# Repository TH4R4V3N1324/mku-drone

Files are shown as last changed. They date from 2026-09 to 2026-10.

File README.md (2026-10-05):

# MKU Drone

Experimental Arduino flight-controller and flight-data-logging workspace.
The repository contains the flight firmware, a standalone IMU logger, Python
utilities for serial tuning and log conversion, and 3D-printable project
models.

This is development hardware and software, not a flight-ready product. Read
the safety notes below before powering motors or ESCs.

## Projects

### [Drone](Drone/README.md)

PlatformIO firmware for an Arduino Uno. The controller:

- Reads an MPU-6050 over I2C and a six-channel PWM receiver.
- Runs experimental roll, pitch, yaw-rate, and hover PID control.
- Mixes the control outputs for four ESCs in an X configuration.
- Supports serial PID tuning and Teleplot-compatible telemetry.

The project README contains the complete pinout, ESC calibration procedure,
control-loop details, known limitations, and tuning instructions.

### [DataLogger](DataLogger/README.md)

PlatformIO firmware for an Arduino Nano. It calibrates an MPU-6050 and writes
fixed-size binary records to a microSD card as `FlightN.bin`. Each record is
40 bytes and contains a timestamp, pitch/roll/yaw, acceleration, and gyro
measurements.

See the project README for the wiring table, binary format, SD-card behavior,
and troubleshooting details.

### [Tools](Tools/)

- [`pid_tuner.py`](Tools/pid_tuner.py) plots live Drone telemetry and sends PID
  commands over the same serial connection.
- [`bin_to_csv.py`](Tools/bin_to_csv.py) converts a DataLogger binary flight
  log into a CSV file, including elapsed time and handling `micros()` rollover.

### [Models](Models/)

3D-printable covers, pads, propeller guards, and test-stand parts for the
hardware.

## Requirements

- [PlatformIO](https://platformio.org/), either the CLI or the VS Code
  extension.
- Python 3 for the desktop tools.
- `pyserial` and `matplotlib` for live PID tuning.

Install the Python dependencies from the repository root:

```text
python -m pip install pyserial matplotlib
```

`bin_to_csv.py` uses only the Python standard library.

## Build and upload

Each firmware project has its own `platformio.ini`. Run PlatformIO from the
project directory you want to build:

```text
cd Drone
pio run
pio run --target upload
pio device monitor --baud 115200
```

For the Nano data logger:

```text
cd DataLogger
pio run
pio run --target upload
pio device monitor --baud 115200
```

PlatformIO normally detects the upload port. If it does not, select the port
in the IDE or add an `upload_port` setting to the relevant
`platformio.ini`.

## Live PID tuning

The Drone firmware can emit Teleplot-compatible telemetry and accept PID
commands over the same serial connection. Enable `TUNE_PID` in
`Drone/src/main.cpp`, upload the firmware, and then run the tuner from the
repository root:

```text
python Tools/pid_tuner.py COM5
```

Replace `COM5` with the board's serial port. If no port is supplied, the tool
lists available serial ports and prompts you to choose one. The default baud
rate is `115200`; it can be changed with `--baud`:

```text
python Tools/pid_tuner.py COM5 --baud 115200 --window 300
```

The tuner plots the selected setpoint, measured value, and PID output while
also forwarding commands typed at its prompt:

| Command | Purpose |
| --- | --- |
| `axis r` | Select roll tuning |
| `axis p` | Select pitch tuning |
| `axis y` | Select yaw tuning |
| `axis h` | Select hover tuning |
| `p <value>` | Set proportional gain |
| `i <value>` | Set integral gain |
| `d <value>` | Set derivative gain |
| `reset` | Clear controller state |
| `show` | Print the active gains |
| `quit` | Exit the tuner |

PID tuning is experimental. Keep propellers removed while changing gains or
testing the control loop.

## Working with flight logs

After stopping or powering down the DataLogger, copy a `FlightN.bin` file from
the microSD card and convert it from the repository root:

```text
python Tools/bin_to_csv.py Flight3.bin
```

This writes `Flight3.csv` beside the input file. To choose a different output
path:

```text
python Tools/bin_to_csv.py Flight3.bin analysis\flight3.csv
```

The logger flushes its buffer every five seconds. Do not remove the SD card
while the logger is running, or the final buffered records may be lost.

## Safety

The Drone firmware is experimental and has not been flight-validated.

- Remove all propellers during setup, wiring, calibration, receiver, IMU,
  ESC, PID, and failsafe testing.
- Keep motors away from people and use a secure test stand where appropriate.
- Power ESCs and motors from a suitable external supply; never power motors
  from the Arduino 5 V pin.
- Verify receiver channel order, IMU orientation, motor numbering, propeller
  direction, ESC arming behavior, and minimum ESC pulses before any powered
  test.
- Treat hover mode as experimental. It is not an arm/disarm mechanism or a
  receiver-loss failsafe.

## Repository layout

```text
Drone/                  Arduino Uno flight-controller firmware
DataLogger/             Arduino Nano binary IMU logger
Tools/                  Python tuning and log-conversion utilities
Models/                 3D-printable hardware models
```

No project license has been specified yet.

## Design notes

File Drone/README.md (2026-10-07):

# Drone Flight Controller

Experimental quadcopter flight-controller firmware for an Arduino Uno. The firmware reads an MPU-6050 IMU and four receiver channels, applies PID corrections, and drives four ESCs through an X-configuration motor mixer.

This is a development prototype, not flight-ready software. Keep propellers removed during development and bench testing, and keep motors away from people.

## Hardware and wiring

- Arduino Uno
- MPU-6050 on I2C at address `0x68`
- Four ESCs and brushless motors
- Receiver with four PWM channels

### Receiver inputs

| Channel | Arduino pin |
| --- | ---: |
| Throttle | 9 |
| Roll | 11 |
| Pitch | 10 |
| Yaw | 8 |
| AUX1 | 12 |
| AUX2 | 13 |

### Motor outputs

| Motor | Arduino pin | Mixer position |
| --- | ---: | --- |
| Motor 1 | 4 | Front left |
| Motor 2 | 5 | Front right |
| Motor 3 | 6 | Rear right |
| Motor 4 | 7 | Rear left |

Connect the receiver and IMU grounds to Arduino ground. Power the ESCs and motors from an appropriate external supply; never power them from the Arduino 5 V pin.

## Requirements

- [PlatformIO](https://platformio.org/)
- Arduino framework for the Uno

The firmware uses the Arduino framework and its built-in `Wire` library for the IMU's I2C connection. No additional PlatformIO libraries are currently required.

## Build and upload

Run these commands from the `Drone` directory:

```text
pio run
pio run --target upload
pio device monitor --baud 115200
```

Select the upload port in PlatformIO or add an `upload_port` setting to `platformio.ini` when automatic port detection does not find the board.

## ESC calibration

ESC calibration is built into the flight-controller firmware and is selected with the `CALIBRATE_ESCS` flag in `src/main.cpp`. When enabled, the firmware sends the same calibration signal to all four ESC outputs (Arduino pins `4-7`): maximum throttle for 15 seconds, followed by minimum throttle for 10 seconds. It then stops and does not enter the normal flight loop.

With propellers removed:

1. Set `CALIBRATE_ESCS` to `1` in `src/main.cpp`.
2. Upload the firmware with the ESCs ready to receive power, but with propellers removed.
3. Power the Arduino and ESCs when prompted by the serial messages, then listen for the ESC confirmation tones.
4. Wait through the 15-second maximum-throttle phase and the 10-second minimum-throttle phase.
5. Power-cycle the ESCs after the firmware reports that calibration pulses are complete.
6. Set `CALIBRATE_ESCS` back to `0` and upload the firmware again before flying.

The calibration routine prints its progress at `115200` baud and intentionally halts after sending both pulse ranges. Keep the motors disconnected or the propellers removed, and use a common ground between the Arduino and ESC signal ground.

## IMU level calibration

"Level" is defined by accelerometer offsets that depend on how the IMU is mounted, so they are measured once and stored in EEPROM. The gyro bias drifts with temperature and is still measured at every boot.

1. Set `CALIBRATE_IMU` to `1` in `src/main.cpp` and upload.
2. Open the serial monitor at `115200` baud.
3. Put a spirit level on the frame (not the table) and shim the drone until the frame is level.
4. Follow the prompts: five rounds of about 6 seconds each. Between rounds, pick the drone up, tilt it around, and set it back down level, then send any key to start the next round. Rounds where the drone moved are repeated.
5. The firmware prints each round, the average, and the spread between rounds. It only saves to EEPROM if all rounds agree within `0.3` degrees. A larger spread usually means a soft surface or a loose IMU mount.
6. Set `CALIBRATE_IMU` back to `0` and upload again before flying.

If it still drifts consistently in hover, adjust `ROLL_TRIM_DEG` and `PITCH_TRIM_DEG` in `src/main.cpp` in steps of about `0.5` degrees. Without position sensing (optical flow or GPS) some drift with air movement is expected.

## Firmware behavior

At startup the firmware initializes serial communication at `115200` baud, wakes the MPU-6050, measures the gyro bias (retrying until the drone is still), loads the level calibration from EEPROM, and seeds the angle estimate from the accelerometer. If no valid calibration is stored, it measures level at boot instead and prints a warning. It then initializes the receiver, starts the ESC output at minimum throttle, and waits two seconds. Arming requires a live receiver link and the throttle seen at minimum first.

The default loop runs the experimental PID control path. It:

1. Reads the IMU and receiver.
2. Estimates vertical velocity from filtered, tilt-compensated accelerometer data.
3. Uses the throttle stick directly and stops all motors when throttle is at or below 5%, unless hover mode is active.
4. Converts receiver commands to roll, pitch, and yaw-rate setpoints.
5. Computes cascaded roll and pitch corrections (angle loop feeding a gyro rate loop), the yaw rate correction, and, when active, the hover PID output.
6. Mixes the commands and writes normalized `0.0-1.0` motor speeds.

### Hover mode

Hover mode is enabled with `AUX1` and uses `AUX2` to command vertical movement:

- Set `AUX1` high while the drone is airborne, the throttle is above 20%, and estimated vertical speed remains below `0.3 m/s` for `0.5` seconds. The firmware captures the filtered throttle value as the hover throttle and resets the hover controller for a bumpless transition.
- While active, `AUX2` commands a climb or descent rate from approximately `-1` to `+1 m/s`. A `0.1 m/s` deadband prevents small stick movements from causing corrections.
- The hover controller adjusts throttle around the captured value, limits the correction to a band around that value, applies a slew rate, and compensates for roll and pitch tilt. Throttle remains constrained between the hover floor and `MAX_THROTTLE`.
- Set `AUX1` low to leave hover mode and return to direct throttle control. The transition ramps from the current hover throttle toward the stick command; moving the stick to the low-throttle cutoff still stops the motors immediately. Hover mode is also not an arm/disarm or receiver-loss failsafe.

Hover mode is experimental. The vertical-velocity estimate is derived from integrated accelerometer data with filtering and leakage, so drift and acceleration bias can affect altitude behavior. Test it with propellers removed first and be ready to disable `AUX1`.

Set `TUNE_PID` to `1` in `src/main.cpp` to enable live PID command handling and telemetry. The `test()` function is available for receiver and mixer checks without PID control; enable it in `loop()` only with propellers removed.

## Live PID tuning

The firmware emits Teleplot-compatible telemetry for the selected axis. The Python helper in `../Tools/pid_tuner.py` plots that telemetry and sends gain changes over the same serial connection.

From the repository root:

```text
python -m pip install pyserial matplotlib
python Tools/pid_tuner.py COM5
```

Use the commands `axis rr` or `axis pr` to select the roll or pitch rate (inner) loop, `axis r` or `axis p` for the roll or pitch angle (outer) loop, and `axis y` or `axis h` for yaw rate or hover tuning. Tune the rate loops first. Use `p <value>`, `i <value>`, and `d <value>` to change gains, `reset` to clear controller state, and `show` to print the active gains. Replace `COM5` with the board's serial port.

## Project structure

```text
include/                 Public firmware headers
  imu.h                   MPU-6050 and orientation interface
  escOutput.h             Timer1 ESC output interface
  motorMixer.h            Quad-X mixer interface
  pid.h                   PID controller
  receiver.h              PWM receiver interface
  serialTuner.h           Runtime PID tuning commands
  calibrationStore.h      EEPROM storage for the IMU level calibration
src/                     Firmware implementation
  main.cpp                Setup, control loop, telemetry, calibration modes, and test loop
  imu.cpp                 MPU-6050 reading, calibration, and complementary filter
  calibrationStore.cpp    EEPROM load/save with checksum and validation
  escOutput.cpp           Timer1 ESC pulse generation
  motorMixer.cpp          Quad-X mixing
  receiver.cpp            Receiver pulse decoding
platformio.ini            PlatformIO configuration
```

## Known limitations and pre-flight work

- There is no explicit arm/disarm state or receiver-loss failsafe beyond invalid channels becoming zero.
- Yaw is integrated from the gyro and will drift without a heading reference.
- The PID gains are experimental and the controller has not been flight-validated.
- Verify receiver channel order, IMU orientation, motor numbering, propeller direction, ESC arming behavior, and minimum ESC pulses with propellers removed.
- Test receiver loss, IMU failure, disarming, and power cycling with propellers removed.

## License

No license has been specified for this project yet.

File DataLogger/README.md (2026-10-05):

# DataLogger

PlatformIO firmware for an Arduino Nano that reads an MPU-6050 and records IMU data to a microSD card as binary records.

## Hardware and wiring

- Arduino Nano with the ATmega328P
- MPU-6050 at I2C address `0x68`
- microSD card module compatible with the SdFat library

### MPU-6050

Connect the sensor using the Nano's standard I2C pins:

| MPU-6050 signal | Arduino Nano pin |
| --- | --- |
| SDA | A4 |
| SCL | A5 |
| VCC | 5V |
| GND | GND |

The firmware uses the I2C address `0x68`, so the sensor's address-select pin must be configured accordingly.

### SD card module

The chip-select pin is fixed to D10. The SPI connections are:

| SD signal | Arduino Nano pin |
| --- | --- |
| CS | D10 |
| MOSI | D11 |
| MISO | D12 |
| SCK | D13 |
| VCC | 5V |
| GND | GND |

## Firmware behavior

At startup, the firmware:

1. Starts serial output at `115200` baud.
2. Starts I2C at 400 kHz and initializes the MPU-6050 for its 1 kHz internal sample rate with the digital low-pass filter disabled.
3. Calibrates the sensor using 2,000 stationary samples. Keep the board still during this step.
4. Initializes the SD card on chip select D10 at a conservative 8 MHz SPI speed for reliable writes.
5. Reads `logNum.txt`, increments its value, and writes the updated value back.
6. Creates a new binary file named `FlightN.bin`, where `N` is the incremented flight number.

If SD initialization or file creation fails, the firmware prints an error and stops in an infinite loop. Existing log files are not overwritten because the flight number is persisted in `logNum.txt`.

The main loop reads the IMU, calculates orientation, and appends one fixed 40-byte binary record to a 128-byte RAM buffer. Each record contains a `uint32_t` microsecond timestamp followed by nine IEEE-754 `float32` values: pitch, roll, yaw, acceleration X/Y/Z, and gyro X/Y/Z. The buffer is written to the card as raw bytes when full and is flushed to the filesystem every five seconds. This avoids CSV conversion and substantially reduces the data size. Serial timing output is disabled in the hot loop because transmitting diagnostics at 115200 baud significantly reduces the maximum logging rate. Remove the SD card only after stopping or powering down the logger so the last buffered data is not lost.

## Binary format

Binary files contain consecutive 40-byte little-endian records with no header:

```text
uint32 timestamp_us
float32 pitch
float32 roll
float32 yaw
float32 accel_x
float32 accel_y
float32 accel_z
float32 gyro_x
float32 gyro_y
float32 gyro_z
```

For example, Python can decode a file with:

```python
import numpy as np

record_dtype = np.dtype([
    ("timestamp_us", "<u4"),
    ("pitch", "<f4"),
    ("roll", "<f4"),
    ("yaw", "<f4"),
    ("accel_x", "<f4"),
    ("accel_y", "<f4"),
    ("accel_z", "<f4"),
    ("gyro_x", "<f4"),
    ("gyro_y", "<f4"),
    ("gyro_z", "<f4"),
])
records = np.fromfile("FlightN.bin", dtype=record_dtype)
```

| Column | Unit | Description |
| --- | --- | --- |
| Timestamp | us | Arduino `micros()` value since boot |
| Pitch | degrees | Complementary-filter pitch estimate |
| Roll | degrees | Complementary-filter roll estimate |
| Yaw | degrees | Gyroscope-integrated yaw estimate; it will drift |
| Accel X/Y/Z | m/s^2 | Accelerometer readings |
| Gyro X/Y/Z | degrees/s | Bias-calibrated and low-pass-filtered angular rates |

The MPU-6050 temperature is read by the IMU class but is not currently written to the binary record.

## Build, upload, and monitor

Install [PlatformIO](https://platformio.org/) through the CLI or the VS Code extension. From this directory, run:

```text
pio run
pio run --target upload
pio device monitor --baud 115200
```

The project is configured for the `nanoatmega328` board and the Arduino framework. The `SdFat` and `SPI` dependencies are declared in `platformio.ini`.

On a successful startup, the serial monitor reports the SD-card status and the name of the active log file. Remove the SD card only after stopping or powering down the logger so the last buffered data is not lost.

## Project layout

```text
include/imu.h       MPU-6050 interface and data accessors
src/imu.cpp         Sensor initialization, calibration, filtering, and orientation
src/main.cpp        SdFat setup, file naming, and buffered binary logging loop
platformio.ini      Nano, framework, monitor, and library configuration
```

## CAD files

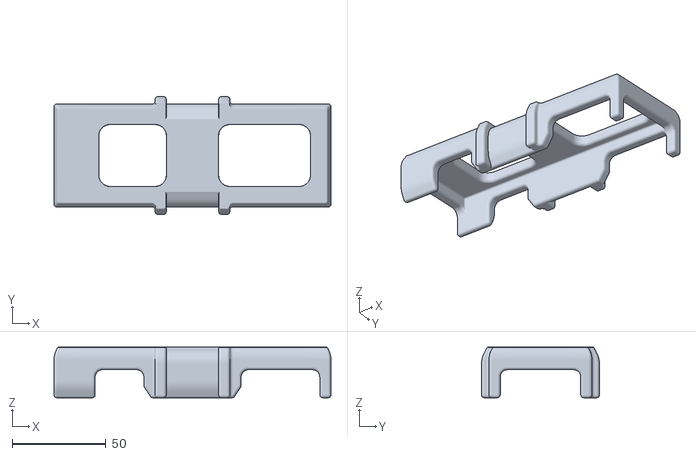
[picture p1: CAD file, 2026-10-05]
Models/Drone/BatteryCoverMk2.stl
148.0 x 63.0 x 27.0

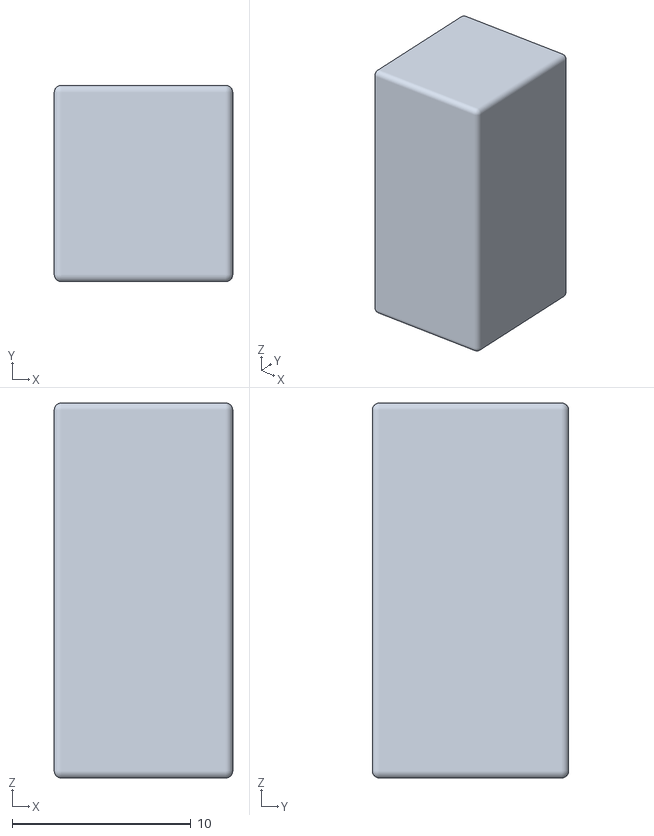
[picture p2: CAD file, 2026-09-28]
Models/Drone/IMU_Pad.stl
10.0 x 11.0 x 21.0

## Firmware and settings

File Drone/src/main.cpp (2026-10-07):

#include <Arduino.h>
#include <Wire.h>
#include <string.h>
#include "imu.h"
#include "motorMixer.h"
#include "escOutput.h"
#include "pid.h"
#include "receiver.h"
#include "serialTuner.h"
#include "calibrationStore.h"

#define TUNE_PID 0        // Set to 1 to enable PID tuning via serial commands
#define CALIBRATE_ESCS 0  // Set to 1 to calibrate ESCs on startup (ensure props are removed)
#define CALIBRATE_IMU 0   // Set to 1 to run the guided IMU level calibration and save it to EEPROM

#if CALIBRATE_ESCS && CALIBRATE_IMU
#error "Enable only one of CALIBRATE_ESCS and CALIBRATE_IMU"
#endif

constexpr float MAX_THROTTLE = 0.85f; // 1850 us, leaving correction headroom

void run();
void disarm();
void test();
[[noreturn]] void haltWithImuError();
#if CALIBRATE_ESCS
void calibrateEscs();
#endif
#if CALIBRATE_IMU
void calibrateImuLevel();
#endif

// ESC signal pins: front left, front right, rear right, rear left (must be on PORTD)
constexpr uint8_t motorPins[ESC_COUNT] = {4, 5, 6, 7};
EscOutput esc;
MotorMixer mixer(esc);
IMU imu;

constexpr uint8_t throttlePin = 9;
constexpr uint8_t rollPin     = 11;
constexpr uint8_t pitchPin    = 10;
constexpr uint8_t yawPin      = 8;
constexpr uint8_t aux1Pin     = 12;
constexpr uint8_t aux2Pin     = 13;
Receiver receiver(throttlePin, rollPin, pitchPin, yawPin, aux1Pin, aux2Pin);

constexpr float ROLL_CORRECTION_LIMIT  = 0.3f;   // PID output range (+/-)
constexpr float PITCH_CORRECTION_LIMIT = 0.3f;   // PID output range (+/-)
constexpr float YAW_CORRECTION_LIMIT   = 0.2f;   // PID output range (+/-)
constexpr float MAX_TILT_ANGLE         = 30.0f;  // deg, full stick roll/pitch
constexpr float MAX_TILT_RATE          = 200.0f; // deg/s, outer angle loop output limit
constexpr float MAX_YAW_RATE           = 180.0f; // deg/s, full stick yaw
constexpr float RATE_D_FILTER_HZ       = 30.0f;  // low-pass on the rate loops' D term only

// Fine level adjustment on top of the EEPROM calibration. If it drifts in hover, trim in
// ~0.5 deg steps; positive values act like holding a little positive roll/pitch stick.
constexpr float ROLL_TRIM_DEG          = 0.0f;
constexpr float PITCH_TRIM_DEG         = 0.0f;
constexpr uint16_t LEVEL_BOOT_SAMPLES  = 2000;   // fallback level measurement at boot if EEPROM is empty (~3 s)

constexpr float HOVER_CORRECTION_LIMIT = 0.25f;  // PID output range (+/-)
constexpr float HOVER_BAND             = 0.25f;  // final throttle stays within hoverThrottle +/- this
constexpr float HOVER_THROTTLE_MIN     = 0.15f;  // floor in hover (must be above the 0.05 motor cutoff)
constexpr float HOVER_SLEW_RATE        = 0.3f;   // max throttle change per second
constexpr float THROTTLE_HANDOFF_RATE  = 1.5f;   // max manual throttle handoff change per second
constexpr float HOVER_MIN_TILT_COS     = 0.7f;   // limits tilt compensation to ~45 degrees
constexpr float ENTRY_MAX_VZ           = 0.3f;   // m/s, must be below this to engage
constexpr float ENTRY_HOLD_S           = 0.5f;   // seconds the conditions must hold
constexpr float ENTRY_MIN_THROTTLE     = 0.2f;   // can't engage hover on the ground
constexpr float CLIMB_DEADBAND         = 0.1f;   // m/s
constexpr float THROTTLE_FILTER_TAU    = 0.3f;   // s, smoothing of stick throttle for capture
constexpr float ACCEL_FILTER_HZ        = 20.0f;  // low-pass on vertical accel
constexpr float VZ_LEAK_TAU            = 2.0f;   // s, drift decay time constant
constexpr float GRAVITY                = 9.80665f; // m/s^2

static bool  hoverActive    = false;
static float vz             = 0.0f;
static float azFilt         = 0.0f;
static float throttleFilt   = 0.0f;
static float hoverThrottle  = 0.0f;
static float hoverCmd       = 0.0f;
static float handoffThrottle = 0.0f;
static bool  throttleHandoff = false;
static float steadyTime     = 0.0f;

constexpr float   ARM_THROTTLE      = 0.08f; // stick above this arms (once unblocked)
constexpr float   IDLE_THROTTLE     = 0.03f; // stick at/below this disarms and unblocks arming
constexpr uint8_t IMU_FAIL_LIMIT    = 25;    // consecutive failed IMU reads (100 ms at 250 Hz) before disarming

static bool    throttleIdle = true;  // motors stopped (disarmed)
static bool    armBlocked   = true;  // must see a valid low throttle before arming (boot, signal loss, IMU failure)
static uint8_t imuFailCount = 0;

PID altitudePID(0.1, 0.0, 0.0, -HOVER_CORRECTION_LIMIT, HOVER_CORRECTION_LIMIT); // PID controller for altitude
// Cascaded attitude control: angle error (deg) -> outer P -> rate setpoint (deg/s) -> inner PID on gyro -> motor correction.
// Roll/pitch gains tuned on a single-axis test rig; yaw is not tuned yet.
PID rollAnglePID(3.0 , 0.0, 0.0, -MAX_TILT_RATE, MAX_TILT_RATE); // outer loop: roll angle -> roll rate setpoint
PID pitchAnglePID(3.0, 0.0, 0.0, -MAX_TILT_RATE, MAX_TILT_RATE); // outer loop: pitch angle -> pitch rate setpoint
PID rollRatePID(0.0045, 0.0008, 0.00002, -ROLL_CORRECTION_LIMIT, ROLL_CORRECTION_LIMIT, RATE_D_FILTER_HZ); // inner loop: roll rate
PID pitchRatePID(0.0045, 0.0008, 0.00002, -PITCH_CORRECTION_LIMIT, PITCH_CORRECTION_LIMIT, RATE_D_FILTER_HZ); // inner loop: pitch rate
PID yawPID(0.004, 0.002, 0.0, -YAW_CORRECTION_LIMIT, YAW_CORRECTION_LIMIT, RATE_D_FILTER_HZ); // yaw rate
SerialTuner tuner(rollAnglePID, rollRatePID, pitchAnglePID, pitchRatePID, yawPID, altitudePID);

unsigned long previousLoopTime;
unsigned long lastTelemetryTime = 0;

void setup() {
  Serial.begin(115200);
  #if CALIBRATE_ESCS
    calibrateEscs();
  #else
    Wire.begin();
    Wire.setClock(400000); // Set I2C clock speed to 400kHz
    Wire.setWireTimeout(3000, true); // Set I2C timeout to 3 ms (value is in us) and reset the bus on timeout

    imu.init();
    #if CALIBRATE_IMU
      calibrateImuLevel(); // does not return
    #endif

    // Gyro bias drifts with temperature, so measure it every boot (works on uneven ground)
    if (!imu.calibrateGyro()) {
      haltWithImuError();
    }

    // Level offsets depend on how the IMU is mounted, so they come from EEPROM
    IMU::LevelCalibration level;
    if (loadLevelCalibration(level)) {
      Serial.println(F("Loaded IMU level calibration from EEPROM."));
    } else {
      Serial.println(F("No saved IMU level calibration - measuring level now, keep the frame level."));
      Serial.println(F("Run CALIBRATE_IMU once for an accurate, repeatable calibration."));
      bool moved = true;
      while (moved) {
        if (!imu.measureLevel(level, LEVEL_BOOT_SAMPLES, moved)) {
          haltWithImuError();
        }
        if (moved) {
          Serial.println(F("Movement detected, retrying - keep the drone still."));
        }
      }
    }
    imu.setLevelCalibration(level);
    if (!imu.resetOrientation()) {
      haltWithImuError();
    }

    receiver.init();
    esc.begin(motorPins); // Timer1 keeps sending min-throttle pulses from here on
    delay(2000);
    mixer.stopAllMotors();
    previousLoopTime = micros();
  #endif
}

void loop() {
  esc.waitForNextCycle(); // fixed ESC_UPDATE_RATE_HZ control loop
  if (TUNE_PID) {tuner.update();}
  run();
  //test();
}

/**
 * @brief Main control loop for the drone
 * @details Reads data from the IMU and receiver, computes PID outputs, and mixes motor speeds
 * @return None
 */
void run() {
  unsigned long now = micros();
  float dt = (now - previousLoopTime) / 1000000.0f;
  previousLoopTime = now;
  if (dt <= 0.0f || dt > 0.1f) dt = 1.0f / ESC_UPDATE_RATE_HZ;

  receiver.readData();

  // Keep flying on the last sample through brief I2C glitches, but disarm if the IMU stays unreachable
  if (imu.readData()) {
    imuFailCount = 0;
  } else if (imuFailCount < IMU_FAIL_LIMIT) {
    ++imuFailCount;
  }
  if (imuFailCount >= IMU_FAIL_LIMIT) {
    disarm();
    return;
  }

  float stickThrottle = receiver.getThrottle();
  bool hoverSwitch = receiver.getAux1() > 0.5f;

  // Filtered stick throttle (used for hover capture)
  throttleFilt += (dt / (THROTTLE_FILTER_TAU + dt)) * (stickThrottle - throttleFilt);

  // Vertical velocity estimate (runs every loop so it's valid on entry)
  float rollRad  = imu.getRoll()  * DEG_TO_RAD;
  float pitchRad = imu.getPitch() * DEG_TO_RAD;
  float tiltCos  = cosf(rollRad) * cosf(pitchRad);

  float azWorld = imu.getAccelZ() * tiltCos - GRAVITY;   // flip sign if your Z axis points down
  const float accelTau = 1.0f / (2.0f * PI * ACCEL_FILTER_HZ);
  azFilt += (dt / (accelTau + dt)) * (azWorld - azFilt);

  vz += azFilt * dt;
  vz -= vz * dt / VZ_LEAK_TAU;                           // dt-independent leak
  if (!hoverActive && stickThrottle <= 0.05f) vz = 0.0f; // on the ground / idle

  // Hover entry / exit
  if (!hoverSwitch) {
    if (hoverActive) {
      handoffThrottle = hoverCmd / fmaxf(tiltCos, HOVER_MIN_TILT_COS);
      handoffThrottle = constrain(handoffThrottle, HOVER_THROTTLE_MIN, MAX_THROTTLE);
      throttleHandoff = true;
    }
    hoverActive = false;
    steadyTime = 0.0f;
  } else if (!hoverActive) {
    bool steady = !throttleIdle && fabsf(vz) < ENTRY_MAX_VZ && throttleFilt > ENTRY_MIN_THROTTLE; // never engage while disarmed
    steadyTime = steady ? steadyTime + dt : 0.0f;

    if (steadyTime >= ENTRY_HOLD_S) {
      hoverActive   = true;
      hoverThrottle = throttleFilt;   // captured hover throttle
      hoverCmd      = hoverThrottle;  // start the slew limiter here (bumpless)
      throttleHandoff = false;
      vz            = 0.0f;
      altitudePID.reset();
    }
  }

  // Throttle
  float throttle;
  float hoverSetpoint = 0.0f;
  float hoverMeasured = vz;
  float hoverCorrection = 0.0f;
  if (hoverActive) {
    float climbRate = receiver.getAux2() * 2.0f - 1.0f;  // +/-1 m/s
    if (fabsf(climbRate) < CLIMB_DEADBAND) climbRate = 0.0f;

    hoverSetpoint = climbRate;
    hoverCorrection = altitudePID.compute(hoverSetpoint, hoverMeasured, dt);

    // Clamp to a band around the captured throttle, above the floor
    float lower  = fmaxf(hoverThrottle - HOVER_BAND, HOVER_THROTTLE_MIN);
    float upper  = hoverThrottle + HOVER_BAND;
    float target = constrain(hoverThrottle + hoverCorrection, lower, upper);

    // Slew limit
    float maxStep = HOVER_SLEW_RATE * dt;
    hoverCmd += constrain(target - hoverCmd, -maxStep, maxStep);

    // Tilt compensation
    throttle = hoverCmd / fmaxf(tiltCos, HOVER_MIN_TILT_COS);
    throttle = constrain(throttle, HOVER_THROTTLE_MIN, MAX_THROTTLE);
  } else {
    if (throttleIdle) {
      // Only arm after a live link has shown the throttle low, so booting or reconnecting with the stick up can't spin the motors
      if (!receiver.hasSignal()) {
        armBlocked = true;
      } else if (stickThrottle <= IDLE_THROTTLE) {
        armBlocked = false;
      }

      if (!armBlocked && stickThrottle > ARM_THROTTLE) {
        rollAnglePID.reset();
        pitchAnglePID.reset();
        rollRatePID.reset();
        pitchRatePID.reset();
        yawPID.reset();
        altitudePID.reset();
        throttleIdle = false;
      }
    } else {
      if (stickThrottle <= IDLE_THROTTLE) throttleIdle = true;
    }

    if (throttleIdle) {
      throttleHandoff = false;
      mixer.stopAllMotors();
      return;
    }

    if (throttleHandoff) {
      float maxStep = THROTTLE_HANDOFF_RATE * dt;
      handoffThrottle += constrain(stickThrottle - handoffThrottle, -maxStep, maxStep);
      throttle = handoffThrottle;
      if (fabsf(stickThrottle - handoffThrottle) <= maxStep) {
        throttleHandoff = false;
      }
    } else {
      throttle = stickThrottle;
    }
    throttle = constrain(throttle, 0.0f, MAX_THROTTLE);
  }

  float rollSetpoint = receiver.getRoll() * MAX_TILT_ANGLE + ROLL_TRIM_DEG;
  float pitchSetpoint = receiver.getPitch() * MAX_TILT_ANGLE + PITCH_TRIM_DEG;
  float yawRateSetpoint = receiver.getYaw() * MAX_YAW_RATE;

  // Outer loop: angle error -> desired rotation rate
  float rollRateSetpoint = rollAnglePID.compute(rollSetpoint, imu.getRoll(), dt);
  float pitchRateSetpoint = pitchAnglePID.compute(pitchSetpoint, imu.getPitch(), dt);

  // Inner loop: track the rate with the gyro directly (roll integrates gyro Y, pitch gyro X)
  float rollOutput = rollRatePID.compute(rollRateSetpoint, imu.getGyroY(), dt);
  float pitchOutput = pitchRatePID.compute(pitchRateSetpoint, imu.getGyroX(), dt);
  float yawOutput = yawPID.compute(yawRateSetpoint, imu.getGyroZ(), dt);

  if (TUNE_PID && millis() - lastTelemetryTime >= 50) {
    lastTelemetryTime = millis();
    const char* axis = tuner.getActiveAxisName();
    float setpointToPrint, measuredToPrint, outputToPrint;
    if (strcmp(axis, "roll") == 0) {
      setpointToPrint = rollSetpoint;
      measuredToPrint = imu.getRoll();
      outputToPrint = rollRateSetpoint;
    } else if (strcmp(axis, "rollrate") == 0) {
      setpointToPrint = rollRateSetpoint;
      measuredToPrint = imu.getGyroY();
      outputToPrint = rollOutput;
    } else if (strcmp(axis, "pitch") == 0) {
      setpointToPrint = pitchSetpoint;
      measuredToPrint = imu.getPitch();
      outputToPrint = pitchRateSetpoint;
    } else if (strcmp(axis, "pitchrate") == 0) {
      setpointToPrint = pitchRateSetpoint;
      measuredToPrint = imu.getGyroX();
      outputToPrint = pitchOutput;
    } else if (strcmp(axis, "yaw") == 0) {
      setpointToPrint = yawRateSetpoint;
      measuredToPrint = imu.getGyroZ();
      outputToPrint = yawOutput;
    } else if (strcmp(axis, "hover") == 0) {
      setpointToPrint = hoverSetpoint;
      measuredToPrint = hoverMeasured;
      outputToPrint = hoverCorrection;
    } else {
      setpointToPrint = 0.0f;
      measuredToPrint = 0.0f;
      outputToPrint = 0.0f;
    }

    //Plot with Teleplot to tune PID parameters
    Serial.print(">Setpoint:"); Serial.println(setpointToPrint);
    Serial.print(">Actual:"); Serial.println(measuredToPrint);
    Serial.print(">Output:"); Serial.println(outputToPrint);
  }

  mixer.mixMotors(throttle, rollOutput, pitchOutput, yawOutput);
}

/**
 * @brief Stop the motors and require a valid low throttle before arming again
 * @details Also leaves hover mode so it can't re-engage until re-armed.
 * @return None
 */
void disarm() {
  hoverActive     = false;
  throttleHandoff = false;
  steadyTime      = 0.0f;
  throttleIdle    = true;
  armBlocked      = true;
  mixer.stopAllMotors();
}

/**
 * @brief Test the receiver-to-mixer path without running the PID controllers
 * @details Uses the transmitter throttle and small normalized attitude commands
 * so each stick can be checked independently with the propellers removed.
 * @return None
 */
void test() {
  receiver.readData();
  receiver.printData();

  float throttle = receiver.getThrottle();
  float roll = receiver.getRoll() * 0.20f;
  float pitch = receiver.getPitch() * 0.20f;
  float yaw = receiver.getYaw() * 0.20f;

  if (throttle <= 0.05f) {
    mixer.stopAllMotors();
    return;
  }

  mixer.mixMotors(throttle, roll, pitch, yaw);
}

#if CALIBRATE_ESCS
/**
 * @brief Calibrate the ESCs by sending a high throttle signal followed by a low throttle signal
 * @details This function should be called once on startup with the propellers removed.
 * It sends a high throttle signal for 15 seconds (power the ESCs during this), then a low
 * throttle signal for 10 seconds, then halts.
 * @return None
 */
void calibrateEscs() {
  esc.begin(motorPins);

  Serial.println(F("ESC calibration: props OFF."));
  Serial.println(F("Sending MAX throttle — power the ESCs now."));
  unsigned long start = millis();
  while (millis() - start < 15000) {
    mixer.setAllMotors(1.0f); // keep refreshing so the output watchdog doesn't drop to min
  }

  Serial.println(F("Sending MIN throttle — listen for confirmation beeps."));
  start = millis();
  while (millis() - start < 10000) {
    mixer.setAllMotors(0.0f);
  }

  Serial.println(F("Calibration pulses sent. Halting — power-cycle to arm normally."));
  mixer.stopAllMotors();
  while (true) {}   // stop here on purpose, don't fall into run()
}
#endif

/**
 * @brief Report an IMU I2C failure and halt
 * @details Called before the ESC output starts, so the ESCs stay unarmed with no signal.
 * @return Never returns
 */
void haltWithImuError() {
  Serial.println(F("IMU I2C error. Check wiring and power-cycle."));
  while (true) {}
}

#if CALIBRATE_IMU
/**
 * @brief Block until a key is sent over Serial, then discard the rest of the line
 * @return None
 */
static void waitForKey() {
  while (Serial.available()) Serial.read();
  while (!Serial.available()) {}
  delay(50);
  while (Serial.available()) Serial.read();
}

/**
 * @brief Guided IMU level calibration, saved to EEPROM
 * @details Measures level several times, with the drone picked up and set down between
 * rounds, and only saves the average if the rounds agree. Rounds where the drone moved are
 * repeated. Open the serial monitor at 115200 baud; ESCs receive no signal while this runs.
 * @return Never returns
 */
void calibrateImuLevel() {
  constexpr uint8_t ROUNDS = 5;
  constexpr uint16_t SAMPLES_PER_ROUND = 4000; // ~6 s per round
  constexpr float MAX_SPREAD_DEG = 0.3f;       // rounds must agree within this to be saved

  Serial.println(F("IMU level calibration."));
  Serial.println(F("Put a spirit level on the FRAME (not the table) and shim it level."));
  Serial.println(F("Measuring gyro bias - keep it still..."));
  if (!imu.calibrateGyro()) {
    haltWithImuError();
  }

  IMU::LevelCalibration rounds[ROUNDS];
  uint8_t round = 0;
  while (round < ROUNDS) {
    Serial.print(F("Round ")); Serial.print(round + 1); Serial.print('/'); Serial.print(ROUNDS);
    Serial.println(F(": set the drone down level and still, then send any key."));
    waitForKey();
    Serial.println(F("Measuring - don't touch it..."));

    bool moved;
    if (!imu.measureLevel(rounds[round], SAMPLES_PER_ROUND, moved)) {
      haltWithImuError();
    }
    if (moved) {
      Serial.println(F("Movement detected - repeating this round."));
      continue;
    }

    Serial.print(F("  pitch ")); Serial.print(rounds[round].pitchOffset, 3);
    Serial.print(F(" deg | roll ")); Serial.print(rounds[round].rollOffset, 3);
    Serial.print(F(" deg | accelZ offset ")); Serial.print(rounds[round].accelZOffset, 3);
    Serial.println(F(" m/s^2"));
    ++round;
    if (round < ROUNDS) {
      Serial.println(F("Pick it up, tilt it around, then set it back down level."));
    }
  }

  IMU::LevelCalibration mean = {0.0f, 0.0f, 0.0f};
  float minPitch = rounds[0].pitchOffset, maxPitch = minPitch;
  float minRoll = rounds[0].rollOffset, maxRoll = minRoll;
  for (uint8_t i = 0; i < ROUNDS; ++i) {
    mean.pitchOffset += rounds[i].pitchOffset / ROUNDS;
    mean.rollOffset += rounds[i].rollOffset / ROUNDS;
    mean.accelZOffset += rounds[i].accelZOffset / ROUNDS;
    minPitch = fminf(minPitch, rounds[i].pitchOffset);
    maxPitch = fmaxf(maxPitch, rounds[i].pitchOffset);
    minRoll = fminf(minRoll, rounds[i].rollOffset);
    maxRoll = fmaxf(maxRoll, rounds[i].rollOffset);
  }
  const float pitchSpread = maxPitch - minPitch;
  const float rollSpread = maxRoll - minRoll;

  Serial.print(F("Average: pitch ")); Serial.print(mean.pitchOffset, 3);
  Serial.print(F(" deg | roll ")); Serial.print(mean.rollOffset, 3);
  Serial.print(F(" deg | accelZ offset ")); Serial.print(mean.accelZOffset, 3);
  Serial.println(F(" m/s^2"));
  Serial.print(F("Spread between rounds: pitch ")); Serial.print(pitchSpread, 3);
  Serial.print(F(" deg | roll ")); Serial.print(rollSpread, 3);
  Serial.println(F(" deg"));

  if (pitchSpread > MAX_SPREAD_DEG || rollSpread > MAX_SPREAD_DEG) {
    Serial.println(F("Rounds disagree - NOT saved. Check the surface is solid and the IMU mount isn't loose, then retry."));
  } else {
    saveLevelCalibration(mean);
    IMU::LevelCalibration check;
    if (loadLevelCalibration(check)) {
      Serial.println(F("Saved to EEPROM and verified."));
    } else {
      Serial.println(F("Save FAILED verification - offsets out of range? Check the IMU mounting."));
    }
  }
  Serial.println(F("Set CALIBRATE_IMU to 0 and re-upload to fly."));
  while (true) {}
}
#endif

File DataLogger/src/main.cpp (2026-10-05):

#include <Arduino.h>
#include <Wire.h>
#include "imu.h"
#include "log_buffer.h"
#include <SdFat.h>
#include <SPI.h>

#define SD_CS_PIN 10

IMU imu;
SdFat sd;
File32 flightLog;

int flightNum = 0;
unsigned long lastLogTime = 0;

struct BinaryLogRecord {
  uint32_t timestampUs;
  float pitch;
  float roll;
  float yaw;
  float accelX;
  float accelY;
  float accelZ;
  float gyroX;
  float gyroY;
  float gyroZ;
};

static_assert(sizeof(BinaryLogRecord) == 40, "Unexpected binary log record size");

LogBuffer logBuffer;

void stopWithError(const __FlashStringHelper *message) {
  Serial.println(message);
  while (true) {
    delay(1000);
  }
}

void setup() {
  // put your setup code here, to run once:
  Serial.begin(115200);
  Wire.begin();
  Wire.setClock(400000); // Set I2C clock speed to 400kHz
  imu.init(0x68); // Initialize IMU with I2C address 0x68
  imu.calibrate(); // Calibrate the IMU
  SPI.begin();
  pinMode(SD_CS_PIN, OUTPUT);
  digitalWrite(SD_CS_PIN, HIGH);
  // Use a conservative SPI speed for reliable writes with typical SD modules.
  if (!sd.begin(SD_CS_PIN, SD_SCK_MHZ(8))) {
    Serial.println("SD card initialization failed on CS D10");
    Serial.println("Expected SPI pins: MOSI D11, MISO D12, SCK D13");
    stopWithError(F("SdFat error: card.begin() failed"));
  }
  Serial.println("SD card initialized");
  Serial.print("FAT type: ");
  Serial.println(sd.fatType());
  
  File32 logNumFile;
  logNumFile = sd.open("logNum.txt", O_RDONLY);
  if (logNumFile) {
    flightNum = logNumFile.parseInt()+1;
    logNumFile.close();
  }

  logNumFile = sd.open("logNum.txt", O_RDWR | O_CREAT | O_TRUNC);
  if (!logNumFile) {
    sd.errorPrint(&Serial, F("Could not create logNum.txt"));
    stopWithError(F("Could not create logNum.txt"));
  }
  logNumFile.println(flightNum);
  logNumFile.close();
  

  char filename[24];
  strcpy_P(filename, PSTR("Flight"));
  itoa(flightNum, filename + 6, 10);
  strcat_P(filename, PSTR(".bin"));
  flightLog = sd.open(filename, O_RDWR | O_CREAT | O_AT_END);
  if (!flightLog) {
    Serial.print("Could not create ");
    Serial.println(filename);
    sd.errorPrint(&Serial, F("Could not create flight log"));
    stopWithError(F("Could not create flight log"));
  }
  logBuffer.attach(flightLog);
  Serial.print("Logging to ");
  Serial.println(filename);
}

void loop() {
  imu.readData();
  
  unsigned long currentTime = micros();

  float pitch = imu.getPitch();
  float roll = imu.getRoll();
  float yaw = imu.getYaw();
  float accelX = imu.getAccelX();
  float accelY = imu.getAccelY();
  float accelZ = imu.getAccelZ();
  float gyroX = imu.getGyroX();
  float gyroY = imu.getGyroY();
  float gyroZ = imu.getGyroZ();

  BinaryLogRecord record = {
    static_cast<uint32_t>(currentTime),
    pitch,
    roll,
    yaw,
    accelX,
    accelY,
    accelZ,
    gyroX,
    gyroY,
    gyroZ
  };
  if (logBuffer.write(
        reinterpret_cast<const uint8_t *>(&record), sizeof(record)) != sizeof(record)) {
    stopWithError(F("Could not buffer flight log data"));
  }

  // Flush the log to the SD card
  unsigned long time = millis();
  if (time - lastLogTime >= 5000) {
    if (!logBuffer.drain(flightLog)) {
      stopWithError(F("Could not write flight log data"));
    }
    flightLog.flush(); // Ensure data is written to the SD card
    lastLogTime = time;
  }
}

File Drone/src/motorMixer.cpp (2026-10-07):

#include "motorMixer.h"

/**
 * @brief Mix the control signals to determine the motor speeds
 * @details Mixes the throttle, roll, pitch, and yaw signals to determine the speed of each motor.
 * Each motor is held at or above MOTOR_IDLE_SPEED so none stops while armed.
 * @param[in] throttle The throttle input (0.0 to 1.0)
 * @param[in] roll The roll input (0.0 to 1.0)
 * @param[in] pitch The pitch input (0.0 to 1.0)
 * @param[in] yaw The yaw input (0.0 to 1.0)
 * @return None
 */
void MotorMixer::mixMotors(float throttle, float roll, float pitch, float yaw) {
    // Simple mixing algorithm for a quadcopter in X configuration
    const uint16_t pulses[ESC_COUNT] = {
        speedToPulse(fmaxf(throttle + roll + pitch + yaw, MOTOR_IDLE_SPEED)), // Front Left
        speedToPulse(fmaxf(throttle - roll + pitch - yaw, MOTOR_IDLE_SPEED)), // Front Right
        speedToPulse(fmaxf(throttle - roll - pitch + yaw, MOTOR_IDLE_SPEED)), // Rear Right
        speedToPulse(fmaxf(throttle + roll - pitch - yaw, MOTOR_IDLE_SPEED)), // Rear Left
    };
    esc.write(pulses);
}

/**
 * @brief Stop all motors
 * @return None
 */
void MotorMixer::stopAllMotors() {
    esc.writeAll(ESC_MIN_PULSE_US);
}

/**
 * @brief Command all motors to the same speed without mixing (used for ESC calibration)
 * @param[in] speed The speed of every motor (0.0 to 1.0)
 * @return None
 */
void MotorMixer::setAllMotors(float speed) {
    esc.writeAll(speedToPulse(speed));
}

/**
 * @brief Convert a normalized motor speed to an ESC pulse width
 * @param[in] speed The speed of the motor (clamped to 0.0 to 1.0)
 * @return Pulse width in microseconds
 */
uint16_t MotorMixer::speedToPulse(float speed) {
    speed = constrain(speed, 0.0f, 1.0f);
    return static_cast<uint16_t>(ESC_MIN_PULSE_US + speed * (ESC_MAX_PULSE_US - ESC_MIN_PULSE_US));
}

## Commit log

2026-09-22 Refactor motor speed handling and initialize motors in setup
2026-09-22 Add detailed documentation for IMU, Motor, MotorMixer, and Receiver classes
2026-09-22 Enhance IMU and PID classes with detailed documentation for methods
2026-09-22 Update IMU class init method to accept I2C address parameter
2026-09-22 Add TODO section with flight preparation tasks and calibration notes
2026-09-22 Refactor IMU class to use dynamic I2C address and improve data handling methods
2026-09-22 Refactor IMU calibration to average gyro offsets and update data reading method
2026-09-22 Refactor receiver to implement interrupt-based pulse width capture and update readChannel method signature
2026-09-22 Implement Motor class initialization and begin method for motor operation
2026-09-22 Refactor test function to improve receiver-to-mixer path and motor control logic
2026-09-23 Initial commit survivability enhancment STL files
2026-09-23 Refactor PID class to include output limits and improve compute logic; update PID instantiation in main.cpp
2026-09-23 Add getter and setter methods for PID gains
2026-09-23 Add live PID tuner script with serial communication and plotting functionality
2026-09-23 Add SerialTuner class for runtime PID gain tuning over Serial
2026-09-23 Implement MotorMixer methods to initialize and stop all motors
2026-09-23 Add Servo library dependency to platformio.ini
2026-09-23 Add IMU class implementation with initialization, calibration, and data reading methods
2026-09-24 Add ESC calibration functionality with receiver signal processing and gyro integration
2026-09-24 Increase gyroscope calibration sample size from 100 to 2000 for improved accuracy
2026-09-25 Enhance IMU class with additional calibration and filtering features
2026-09-25 Enhance IMU class with additional filtering, calibration improvements, and updated initialization
2026-09-25 Add throttle constraint to run function to prevent instability at higher speeds
    [main.cpp]
2026-09-25 Set I2C clock speed to 400kHz in setup function
2026-09-28 Added IMU_Pad model
    [IMU_Pad.stl]
2026-09-28 Fix receiver pin assignments for roll and yaw channels in main.cpp and README.md
    [main.cpp]
2026-09-28 Add ESC calibration feature and update README with instructions
2026-09-28 Increase ESC calibration duration for better reliability
2026-09-30 Refactor main.cpp to initialize IMU and read orientation data; update platformio.ini for consistency
2026-09-30 Add IMU calibration in setup function for improved accuracy
2026-09-30 Invert pitch channel value in readData function for correct orientation
    [receiver.cpp]
2026-09-30 Refactor integral clamping in PID compute method for improved accuracy
2026-09-30 Implement hover control logic with altitude PID for improved stability
    [main.cpp]
2026-09-30 Add accelZOffset for improved accelerometer calibration and data accuracy
2026-10-01 Update to platform ini file add SD and SPI
2026-10-02 Improve SD card initialization and error handling in setup
    [main.cpp]
2026-10-02 Add accelZOffset for improved IMU calibration and data accuracy
2026-10-02 Add new STL models for Drone and Test Stand components
    - Introduced PropGuardMk2, UnoCoverBody1, and UnoCoverLid1 for the Drone.
    - Added PivotArm, PivotBlock, PivotBush, and StiffeningBar for the Test Stand.
    [IMU_Pad.stl]
2026-10-02 Enhance hover mode functionality with throttle handoff and improved transition control
2026-10-02 Implement throttled flushing of flight log to SD card every 5 seconds
2026-10-05 Add BatteryCoverMk2 STL model and remove obsolete BatteryFrame STL model
    [BatteryCoverMk2.stl]
2026-10-05 Optimize IMU initialization by disabling DLPF for maximum bandwidth and setting sample rate to 1 kHz
2026-10-05 Set IMU sample rate to 1KHz
2026-10-05 Refactor tune PID to run at a fixed 50Hz rate
    [main.cpp]
2026-10-05 Add hysteresis deadband logic to remove motor twitching when idle
    [main.cpp]
2026-10-05 Refactor initialization order so that motor noise indicates completed init
    [main.cpp]
2026-10-07 Replace Servo library with Timer1-driven 250Hz ESC output
    The Servo library only refreshes ESCs at 50Hz, adding up to 20ms of
    output latency. EscOutput drives all four ESC pins from Timer1
    interrupts at a fixed 250Hz, applies all four pulse widths atomically
    each cycle, and falls back to min throttle if not updated for 200ms.
    The control loop is now paced to the same 250Hz cycle.
    MotorMixer now only does the quad-X mixing; the Motor class is removed.
    [escOutput.cpp, escOutput.h, main.cpp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]
2026-10-07 Add deadbands to controller inputs to prevent unintentional movement commands
    [receiver.cpp]
2026-10-07 Refactor roll, pitch and yaw correction limits as constants
    [main.cpp]
2026-10-07 Rework IMU filtering and fix accelerometer calibration
    Increase gyro range to +/-1000 deg/s and accel range to +/-8g so fast
    rotations and motor vibration don't clip. Remove the software gyro
    low-pass filter, which stacked delay on top of the DLPF, and set the
    DLPF to 98Hz to stay below the 125Hz Nyquist of the 250Hz loop.
    Replace the fixed 0.98 complementary filter constant with a 1s time
    constant so accelerometer correction no longer depends on loop rate
    and vibration is filtered out of the angle estimate.
    Fix calibration computing accel angle offsets with mixed g and m/s^2
    units, which underestimated them by ~10x. Calibration and runtime now
    share one accelAngles() helper.
    [imu.cpp, imu.h]
2026-10-07 Add PID reset when transitioning throttleIdle states
    [main.cpp]
2026-10-07 Add IMU timeout and data validation
2026-10-07 Add motor idle floor to prevent motors stopping while armed
    mixMotors() now holds every motor at or above MOTOR_IDLE_SPEED (5%),
    so a large correction at low throttle can no longer stop a motor
    mid-air and risk ESC desync. stopAllMotors() and ESC calibration still
    command a full stop.
    [motorMixer.cpp]
2026-10-07 Switch roll and pitch to cascaded angle/rate control
    Roll and pitch now use an outer P loop on angle that outputs a rate
    setpoint, feeding an inner PID loop on the gyro rate. Damping now
    comes from the gyro directly instead of differentiating the filtered
    angle, and the inner loop rejects disturbances within one cycle.
    PID gains an optional low-pass filter on the D term only, used by the
    rate loops at 30Hz. The serial tuner can select the rate loops
    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
2026-10-07 Add arming and IMU failure safety checks
    Require a live receiver link and a low throttle before arming, so
    booting or reconnecting with the stick raised can't spin the motors.
    Hover mode can no longer engage while disarmed.
    IMU::readData() now reports I2C failures. After 100ms of consecutive
    failures the drone disarms instead of flying on stale attitude data.
    [imu.cpp, imu.h, main.cpp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]
2026-10-07 Clean up receiver channel decoding and rescale stick deadband
    Replace six copies of the pulse validity check with one helper and
    named constants, and remove the aux deadband lines that ran before
    aux1/aux2 were assigned. The deadband now rescales so output rises
    smoothly from 0, which also makes the 0.03 disarm threshold reachable.
    [receiver.cpp]
2026-10-07 Clean up IMU reads and halt on calibration failure
    Share one raw-read function between calibrate() and readData(), read
    register bytes in a defined order, and make scale constants static
    constexpr to save RAM. calibrate() now reports I2C failure and setup
    halts instead of flying with zero offsets. Fix stale comments.
    [imu.cpp, imu.h, main.cpp]
2026-10-07 Add guided IMU level calibration stored in EEPROM
    CALIBRATE_IMU runs a multi-round level calibration with motion
    rejection and only saves to EEPROM if the rounds agree within 0.3 deg.
    Normal boot now measures only the gyro bias (retrying until still),
    loads level offsets from EEPROM, and seeds the angle estimate from the
    accelerometer. Falls back to boot-time level measurement if nothing
    valid is stored. Add ROLL_TRIM_DEG / PITCH_TRIM_DEG for fine trim.
2026-10-07 Add PMW3901 optical flow driver and move receiver off SPI pins
    The receiver used D8-D13, which includes the Uno's hardware SPI pins.
    Receiver channels now map to any pin-change port, so the sticks move to
    A0-A3 and the aux switches to D2/D3, freeing D10-D13 for the PMW3901.
    The flow sensor is initialised at boot; if it is missing the drone
    still flies without drift hold.
2026-10-07 Add optical flow drift hold and flow check mode
    When airborne (hover mode, or stick throttle above 0.2), the PMW3901
    flow is read at 50 Hz, gyro rotation is removed, and two PI loops nudge
    the roll/pitch angle setpoints to drive ground drift to zero. An axis
    is released while its stick is moved and on low surface quality.
    CHECK_FLOW plots flow against the gyro on the bench to set the sensor's
    orientation and scale. Drift gains are tunable as axis dr/dp. READMEs
    cover the new wiring, the flow check, and drift hold.
2026-10-07 Cut motors when tilt exceeds 45 degrees
    If roll or pitch stays beyond 45 degrees for 0.1 s while armed, in
    normal or hover mode, the motors are disarmed and re-arming requires
    the throttle stick at zero first. Covers flips, collisions and the
    drone getting stuck against an obstacle.
2026-10-08 Fixed loop rate to 500hz
2026-10-08 Updated prop guard model
2026-10-13 Fixed opticalflow direction to match physical mounting
2026-10-13 Added method to enable breakout board LEDs
2026-10-13 Calibrate optical flow mounting and remap receiver pins
    Flip both flow signs and raise FLOW_RAD_PER_COUNT to 1.9e-3 after
    CHECK_FLOW showed flow running opposite to rotation at ~0.66 gain.
    Rotation now cancels (gain ~1.0, corr +0.94 on both axes).
    Lower drift hold P from 8 to 6 to stop a small oscillation, and move
    throttle/roll/pitch to A2/A0/A1 to match the receiver wiring.
2026-10-13 Hold ESC pins low during setup and stop below calibrated minimum
    The ESC signal pins floated through IMU calibration while the ESCs were
    already powered, so they could arm on noise. Drive them low from the
    start of setup(); esc.begin() stays at the end so the arming tones
    still mark calibration done.
    Stopped motors now get a 950 us pulse (ESC_STOP_PULSE_US), below the
    1000 us calibrated minimum, so interrupt latency that lengthens pulses
    can't spin them. Throttle still maps to 1000-2000 us.
2026-10-14 Add pre-arm checks, frozen IMU detection and ground I-term reset
    - Refuse to arm unless level, the IMU is responding and hover is off
    - Treat a run of identical IMU samples as a failure (MPU-6050 brownout)
    - Hold PID integrals at zero until airborne to avoid takeoff flips
    - Let the throttle stick disarm while in hover mode
    - Lower max tilt to 15 deg and crash angle to 30 deg
    - Raise airborne/hover-entry throttle to 0.5 and add drift-hold I gain
2026-10-16 Update README.md to include current pinouts for the receiver
2026-10-16 Fix DataLogger RAM overflow corrupting IMU data
    The stack was overflowing into the imu object (only 280 bytes free),
    corrupting its scale constants, offsets and I2C address, so every log
    held garbage values.
    - Switch to the drone's IMU driver (static constexpr constants, I2C
    error checks, frozen-data detection)
    - Remove LogBuffer and write records straight to the file; SdFat
    already buffers them in its sector cache
    - Move Serial strings to flash with F()
    - Stop if the IMU fails at startup, and skip records on failed reads
    - Print per-loop execution time for timing checks
2026-10-21 Invert yaw value during deadband application in readData function
2026-10-21 Fix control loop overruns and add loop profiling
    The armed loop took ~4.4 ms, longer than the 4 ms ESC period, so it ran
    back to back at an irregular ~230 Hz. It now takes ~2.7 ms (worst ~3.3 ms)
    and holds a steady 250 Hz.
    - MEASURE_LOOP flag: prints loop time, overruns, per-section times and
    receiver interrupt rate; waitForNextCycle() reports overruns
    - PID: precompute integral limits and D-filter constant, single-division
    filtered derivative, skip the D path when kd is 0
    - IMU, receiver, run(): multiply by precomputed reciprocals instead of
    dividing; accel angles use raw counts (atan2 is scale-invariant)
    - Spread work that doesn't need every loop over a 6-loop schedule:
    flow read,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
2026-10-21 Fix PID integral windup and raise yaw authority
    Yaw lagged and kept turning after the stick was released: with the output
    saturated, the integral still ran up to its clamp and then had to unwind.
    - PID: freeze the integral while the output is saturated in the direction
    the error pushes (conditional integration); applies to every axis
    - Yaw: P 0.004 -> 0.008, output limit 0.2 -> 0.3
    - TUNE_PID telemetry also plots the active PID's I-term (>ITerm)
    - AIRBORNE_THROTTLE and ENTRY_MIN_THROTTLE 0.5 -> 0.2 so the I-terms
    run through the whole hover range
2026-11-02 Update READMEs to match current firmware and flight status
    - Drone: document the 250 Hz loop and task scheduling, arming and
    pre-arm checks, safety cutoffs (receiver loss, IMU failure, crash
    angle, ESC watchdog), anti-windup, build-time flags and MEASURE_LOOP;
    fix stale DRIFT_MIN_THROTTLE, flow rate and drift gain references
    - DataLogger: describe the 500 Hz timer loop, 98 Hz DLPF, gyro-only
    calibration, direct SdFat writes and skipped records on IMU failure
    - Root: add CSV_analyser.py and FFT_Anaylsis_Code.m, rate-loop tuner
    axes, and the current Models listing
    - Mark the flight controller, hover mode and drift hold as
    flight-validated; yaw remains untuned
2026-11-02 Remove unused LogBuffer and fix DLPF loop-rate comments
    LogBuffer has been unused since the DataLogger switched to direct SdFat
    writes. The DLPF comments referred to the wrong loop rates: the Drone
    runs at 250 Hz and the DataLogger at 500 Hz.
